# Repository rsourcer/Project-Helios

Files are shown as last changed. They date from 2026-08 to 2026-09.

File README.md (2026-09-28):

# Helios-Michaelson-Interferometer
Digitally assisted optical platform using a Michaelson Interferometer allowing for magnetostriction testing using red laser light. 

A **Michaelson Interferometer** is a typical configuration for interferometry in which a laser first hits a beamsplitter. The light is roughly equally split, travelling in two perpendicular directions, but hit a mirror, which bounces both beams back to the beamsplitter. This makes the light recombine in a strange way, creating a rippling effect and travelling in a completely new direction. The change in light intensity caused by these ripples as one of the mirrors moves can be measured by a photodiode and can be used to calculate the wavelength of the light to, in theory, calculate the phase shift caused by a magnetic field caused by a solenoid. This is done with the formula
$$\lambda = \frac{2d}{\Delta N}$$ , where d is the distance the mirror moves by and ΔN is the number of fringes observed.
In turn, it is therefore possible to measure a **magnetostriction** strength using a mirror attached to a metal rod inside a solenoid - as the magnetic field affects the rod, the mirror moves, and the fringes shift in a measurable manner.
<div align="left">
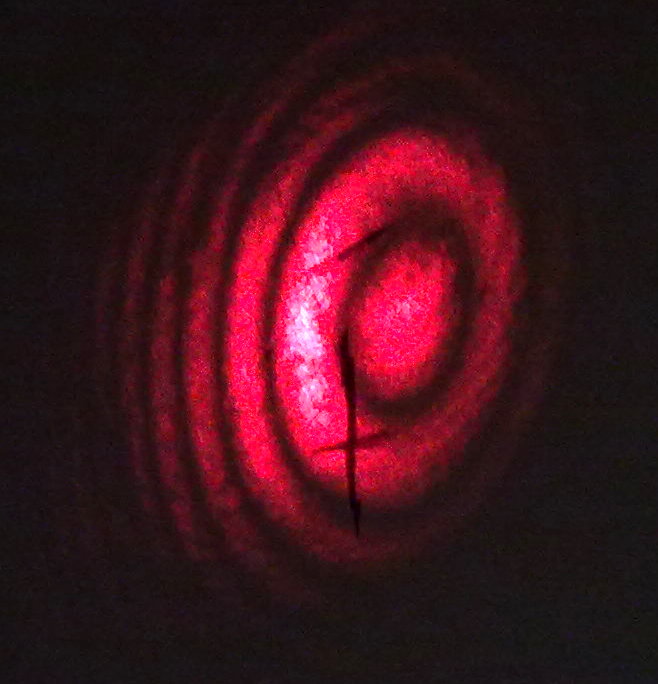
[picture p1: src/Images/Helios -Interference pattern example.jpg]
  
</div>
Fig 1.01: Example of an enlarged fringe image produced by a michaelson interferometer. (Wikipedia Commons) [1]

The aim of this project is therefore to detect fringe shifts caused magnetostrictive strain. The object's technical objective is to build a Michaelson Interferometer system which can:
- Takes a laser diode's output
- Splits the light through a beam splitter component
- Recombine light with the help of two mirrors, creating the interferometric patterns crucial to the experiment
- Project the image onto a photodiode or expand it with a lens
- Detect interference patterns using a TIA photodiode system as one of the mirrors moves parallel to the laser light.
- Detect magnetostriction through fringe movements spotted by the photodiode's signal output\
See JOURNAL.md for further constraints and objectives.

# Hardware:

|  |  |
|:---|:---|
| **Optics** |  |
| Laser Diode | Budget 650nm Laser|
| Beam Splitting Glass | Budget 50:50 Cube Beamsplitter|
| Mirrors | 2x λ/10 Flatness Protected Silver, Ø1/2" Mirror |
| Lens | 160/0.17 10X Achromatic Objectives Lens |
|**Electronics** | |
| Board | Arduino Uno ATmega328P |
| Amplifier | MCP601-I/P |
| Capacitor | 100 pF Capacitor | 
| Photodiode | BPW34 |
| Resistors | 100kΩ 25 Turn Trimmer + 100Ω Fixed Resistor|
| Rod | Nickel Rod |
| Solenoid | Made from Copper Wire |
| Power Supply | DC Variable Power Supply |
|**Mechanical** | |
| Micrometer | 0-13mm Micrometer Flat/Ball Head |
| Screws | 10x Assorted M3, M5, M6 Screws w/Nut & Washers, Heat Insert set |
| Brackets, mounts | 3D Printed from PETG-CF |
|**Miscellaneous** | |
| Breadboard | Adapted CNC MDF 3040 Spoilboard, 30x36cm |
| Image Surface | Grid Paper |

# Acronym List:

This is a reference to understand every acronym used

Optical\
BS: Beamsplitter\
M1: Mirror 1 (Micrometer mirror)\
M2: Mirror 2 (Solenoid mirror)\
PD: Photodiode\
Electronics\
PS: Power Supply\
NR: Nickel Rod\
S or SLD: Solenoid\
AMP/TIA: Trans-Impendence Amplifier\
Mounts\
BSM: Beamsplitter mount\
LDM: Laser diode mounting bracket\
LMB: Lens mounting bracket\
SMM/SMB: Solenoid mirror mounts/bracket\
MMM: Micrometer mirror mounts\
PMB: Photodiode mounting bracket\
SPB: Spoilboard

# 3D Models
- To print all components, the stl files were used and sliced into gcode- this may lead to inconsistencies when using the step file, as it was converted online! Please beware of this if trying to print models.\
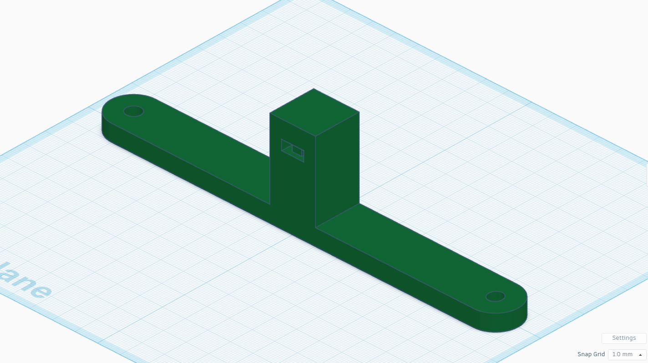
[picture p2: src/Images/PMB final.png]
  \
  Fig 1.02: Finalized version of the PMB.\
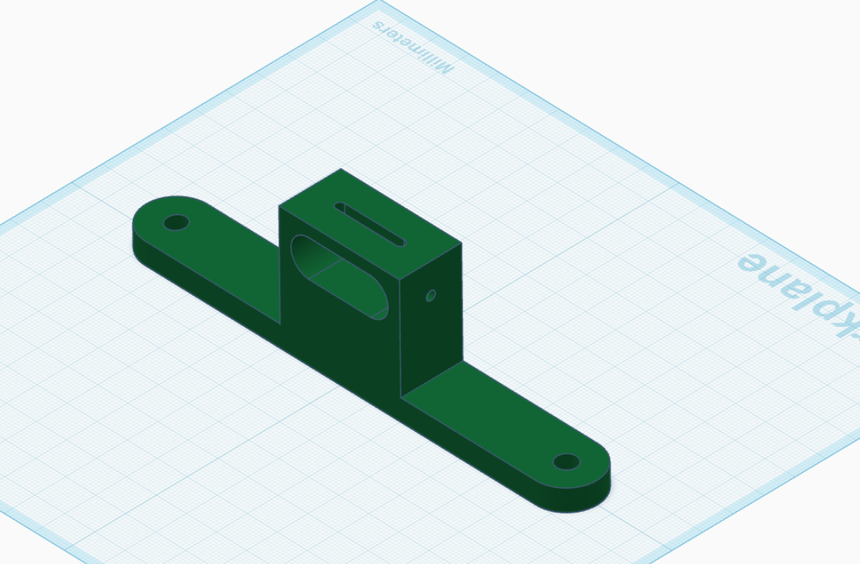
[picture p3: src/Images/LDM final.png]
    \
  Fig 1.03: Finalized version of the LDM.\
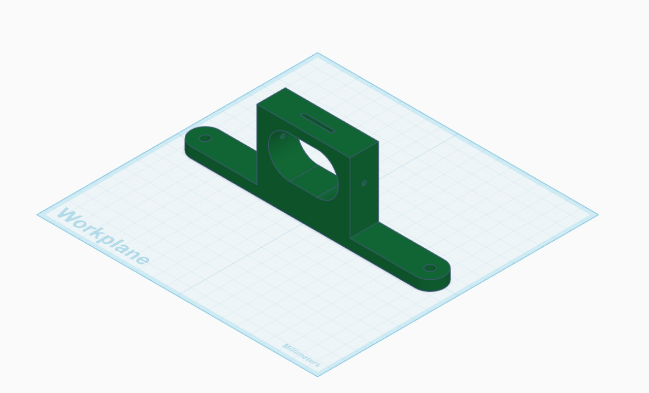
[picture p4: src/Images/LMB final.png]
    \
  Fig 1.04: Finalized version of the LMB.\
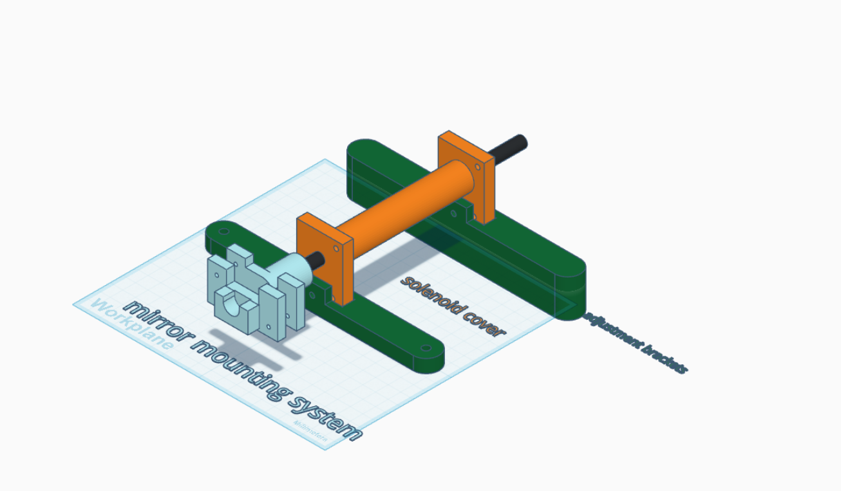
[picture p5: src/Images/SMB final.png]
    \
  Fig 1.05: Finalized version of the SMB.\
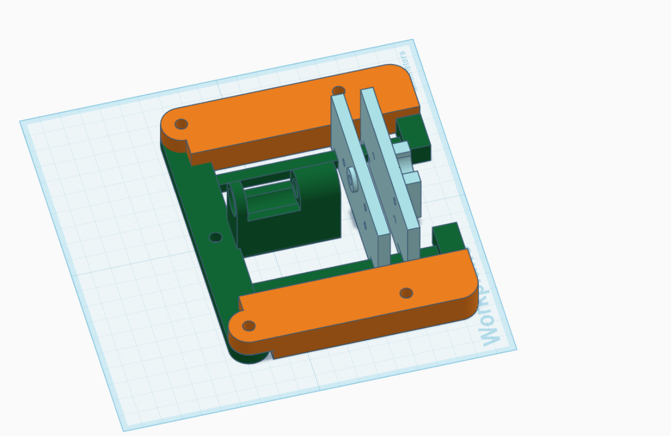
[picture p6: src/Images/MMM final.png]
    \
  Fig 1.06: Finalized version of the MMM.\
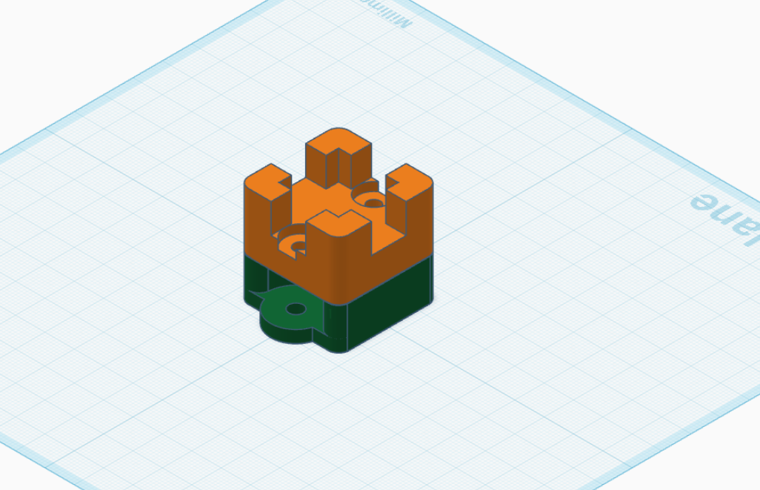
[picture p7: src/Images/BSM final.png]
    \
  Fig 1.07: Finalized version of the BSM.\
# Testing Checklist

**Preparation**
---
1: Prepare a clean, flat surface to work on.\
2: Use a vacuum cleaner on work surface and isolate ventilation of room to ensure no dust enters. Ideally, use an air purifier to mitigate dust further.\
3: Wear disposable gloves to ensure touched components remain dust free.\
4: Gently take out the beam splitter out of container, while holding its edges. Avoid contact with flat surface.\
5: Place the beam splitter flat onto the BSM mount.\
6: Gently take out the mirror while holding its circular edge - a plier may be used to facilitate removal from the case and precise insertion.\
7: Place the mirror onto the MMM mirror mount whilst avoiding contact between the plastic mount and the silvered surface.\
8: Repeat steps 7-8, but place the mirror onto the SMB mirror mount instead.\

**Calibration**
---
1: Connect ATMega32P to power.\
2: Using the spoilboard ruler markings, ensure L1 (distance from mirror 1 to beamsplitter) is within a millimeter's difference from L2 (distance from mirror 2 to beamsplitter) and that the micrometer is not fully extended.\
3: Use piece of cut paper to determine where laser images are at key points (beside the laser origin and in front of the lens)\
4: Align accordingly using screw mounts until all images land at the same place (on the beam)\
5: If needed, adjust lens position precisely using translation screws until the recombined beam is at the lens center.\
6: If needed, adjust laser focal length with focal adjustment guide until the beam does not visibly diverge or converge at a point, using the lens image and cut paper to measure laser size.

**Electronic Measurement**
---
1: If unconnected, connect the Photodiode anode to the 5V AtMega32P pin.\
2: Connect the GND wire from the op-amp's Pin 3 to the GND AtMega32P pin.\
3: Power on the AtMega32P and turn on the power supply.\
4: Precisely move mirror 1 using the permitted movement in the MMM until the signal modulation drops significantly on screen, making sure that the laser dot image hits the photodiode - this ensures the photodiode is measuring dips produced by Michaelson fringes!\
5: Gradually set power supply current to 10A in about 5 seconds. Be sure to remain as constant as possible.\
6:Observe change produced in photodiode signal.\
Further explanations are in the JOURNAL.md file - I recommend checking it out! 

# Electronics
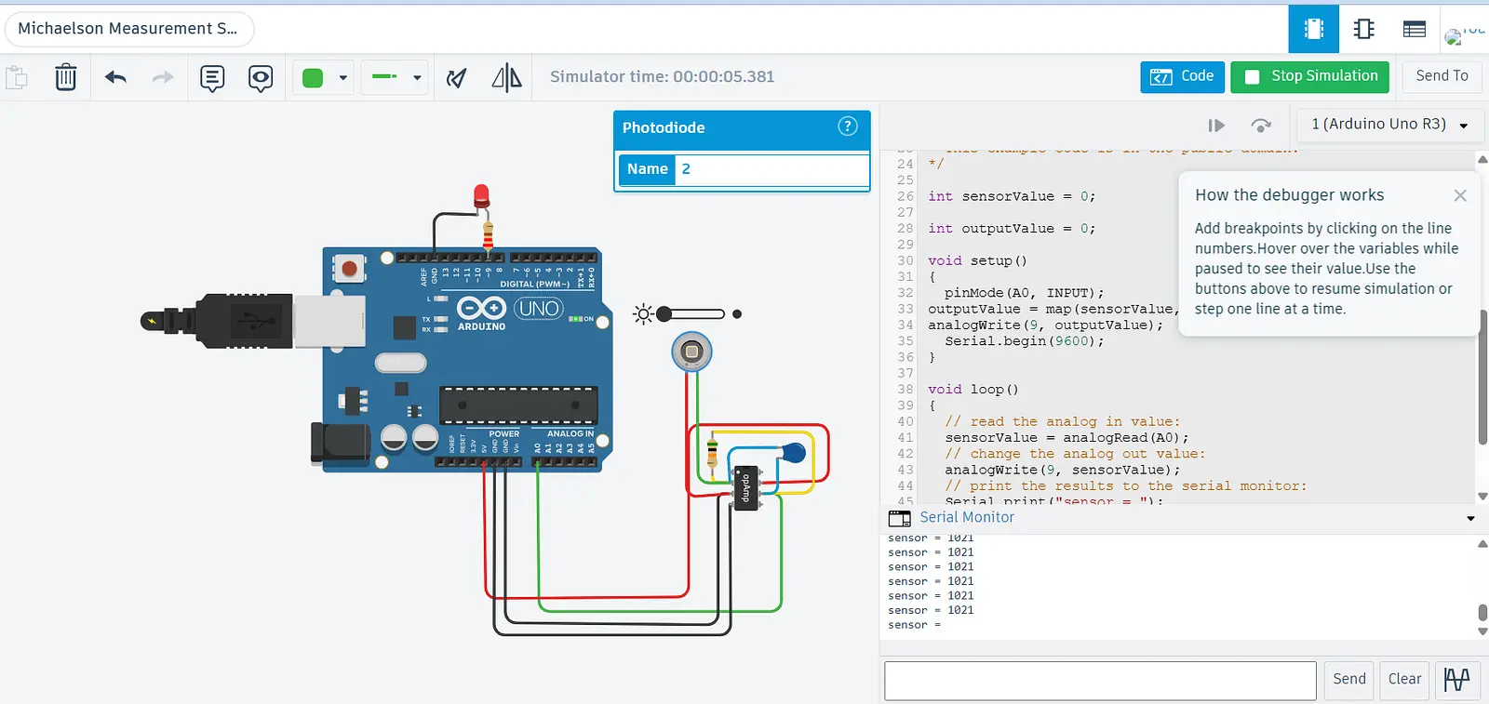
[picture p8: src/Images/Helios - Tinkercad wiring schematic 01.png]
  
  Fig 1.08: Original theoretical wiring for TIA amplification system for a photodiode.
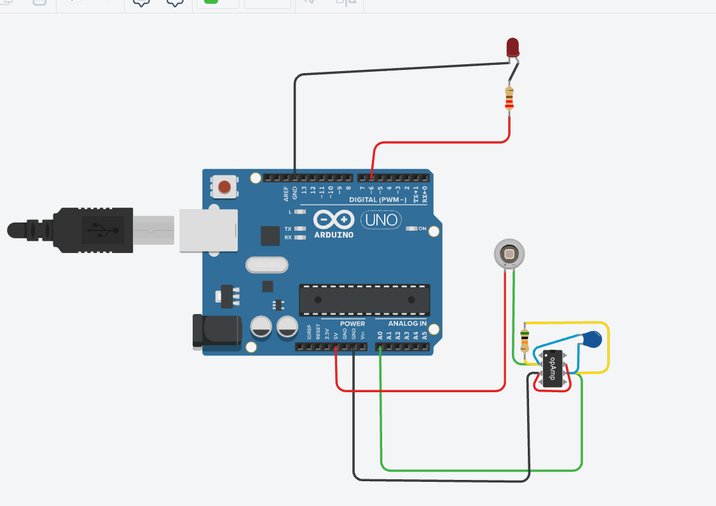
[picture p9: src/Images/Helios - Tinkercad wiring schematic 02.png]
 
  Fig 1.09: Real-world wiring for TIA amplification system used in trial results.

There are two electronic circuits which make up the interferometry platform. The first is pictured above - it passes 5V through an MCP601 op-amp paired with a BPW34 photodiode to receive and amplify light signals, connected to the microcontroller - also connected to the 3.3V power source is 100Ohm resistor in series with a 650nm red laser diode.

The second is a 10A,30V rated power supply in CC mode running through a 120 turn, 25ft copper wire to create a solenoid magnetic field, which is used to measure magnetostriction inside a nickel rod:\
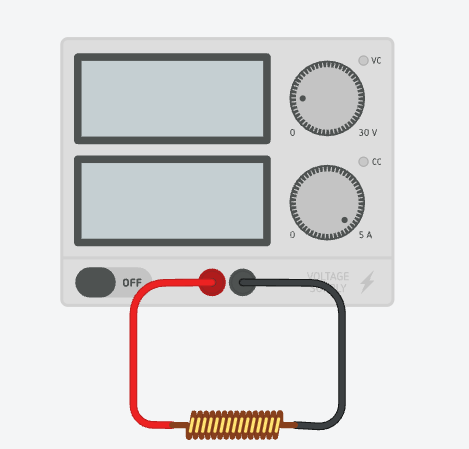
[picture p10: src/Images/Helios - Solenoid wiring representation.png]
 \
  Fig 1.10: Electrical wiring diagram of DC power supply with solenoid.
  
# Results
Following the Electronic Measurement protocol:
- A significant and repeated drop in signal strength of about 1.0(+-0.5) has been observed when the power supply current is increased at a steady rate.
- When the current is increased to 10A very quickly, the signal strength drops instantaneously.
- When the photodiode is fully covered, increasing the current does not affect it in any way.
Due to these factors, qualitative proof of the magnetostrictive properties of a nickel rod has been established beyond reasonable doubt, as the phase shift must can only have been caused by mechanical movement.
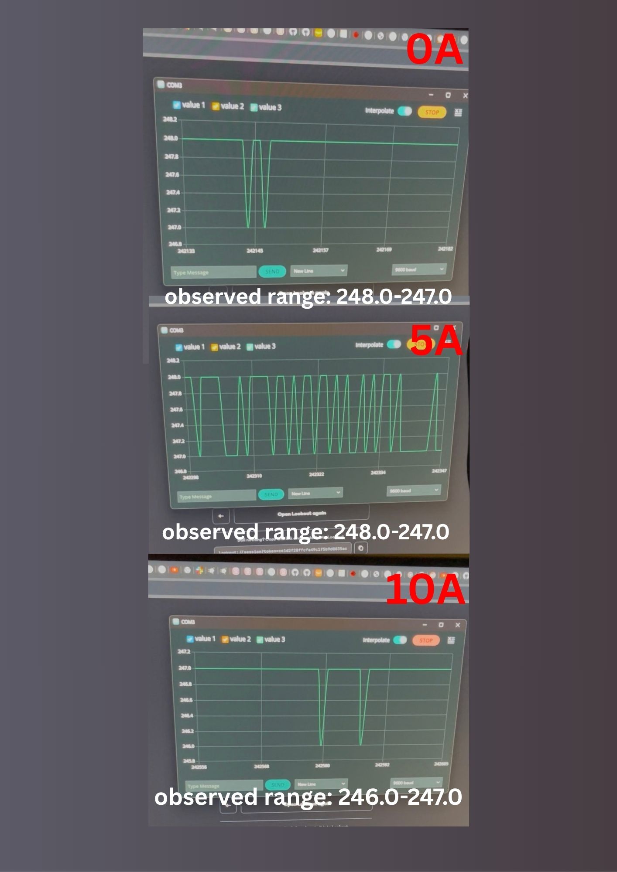
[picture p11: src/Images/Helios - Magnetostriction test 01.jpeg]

Fig 1.11: Representation of obtained results from magnetostriction, trial run 1.

Sources for this document:\
[1]

[Interference pattern Michelson Interferometer](https://commons.wikimedia.org/wiki/File:Interference_pattern.jpg) by Cecilia.p under Creative Commons Attribute 3.0 Unported

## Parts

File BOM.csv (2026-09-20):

Item Name | Qty | Price (CAD) | Item link | Notes
Thorlabs PFSQ10-03-P01 | 2 | $102.85 | https://www.thorlabs.com/item/PF05-03-P01 | ?/10 surface flatness, ?1/2" Protected Silver Mirror with 97% Reflectance @450nm. This item is priced in USD at 36.89 USD per mirror, so the Canadian price is accurate as of 11/08/2026. Shipping costs apply (35.45 USD -> $49.40)
Beam Splitter Cube, Optical Glass Dichroic Prism Ratio 50:50 Spectrome Sicence | 1 | $43.47 | https://www.amazon.ca/gp/product/B0B34FK2GF | K8 Cristal Cube Beamsplitter.
ELEGOO UNO Project Basic Starter Kit with Tutorial and UNO R3 | Compatible with Arduino IDE | 1 | $29.99 | https://www.amazon.ca/gp/product/B0834W2NKQ | ELEGOO Arduino UNO R3 board including jumper cables and spare resistors.
10x10PCS 1KV High Voltage Ceramic Capacitor Kit | 100pF 220pF 330pF 470pF 1nF 2.2nF 3.3nF 4.7nF 10nF 22nF | 1 | $10.99 | https://www.amazon.ca/gp/product/B0C5SKHXYD | Capacitor Kit with 10 sets of 10 capacitors, ranging from 100pF to 22nF.
MCP601-I/P | 3 | $2.94 | https://www.digikey.ca/en/products/detail/microchip-technology/MCP601-I-P/305930 | Op-Amp with single rail 2.7-6V support - all used pins match to the IC 741. DigiKey products are subject to 15$ shipping cost for both items as they amount to under 100$ CAD in purchases.
BPW34 | 2 | $5.78 | https://www.digikey.ca/en/products/detail/ams-osram-ag/BPW34/607274 | Photodiode rated for 850nm, 20ns. DigiKey products are subject to 15$ shipping cost for both items as they amount to under 100$ CAD in purchases.
uxcell 10Piece 3296W-104 100K Ohm Trimmer Pot Cermet Potentiometer | Variable Resistors | 1 | $12.50 | https://www.amazon.ca/gp/product/B00D2JRALS | 10x set of 25 turn, 100k Ohm Trimmers.
Inside Micrometer, 0-13mm Micrometer Flat/Ball Head | 1 | $18.67 | https://www.amazon.ca/gp/product/B083KHFKZ6 | 0-13 0.01mm Micrometer Head
DM-WJ002 185 Biological Microscope Objective Lens Silver 10X Achromatic Objectives Lens 160/0.17 | 1 | $21.96 | https://www.amazon.ca/gp/product/B082P3P953 | 10X Aluminium Achromatic Objective Lens.
Genmitsu 3040 MDF Spoilboard, Work with 3040 Y-Axis Extension Kit, 3018 CNC Upgraded Accessories Compatible with Most 3018, 3018-PRO/ 3018-MX3, 30 x 36 x 1.5cm (11.8'' x 14.1'' x 0.6'') | 1 | $29.74 | https://www.amazon.ca/Genmitsu-Spoilboard-Extension-Accessories-Compatible/dp/B08VN6HXPD | 30x36cm M5-6 compatible Spoilboard. Product is on sale as of 11/08/2026 and was ordered for this price. Usual price is 34.99$ CAD.
SHONAN Nickel Anode- 7.87"x0.3"(Diameter) Nickle Anode, Pure Nickel Bar, Nickel Rod for Nickel Electroplating Solution, 3.4oz 99.6% | 1 | $23.10 | https://www.amazon.ca/gp/product/B083LJWQYG | 7.87"x0.3" 99.6% Solid Nickel Rod.
123109-18GA Copper Wire 25FT 14LB | 1 | $9.99 | https://www.amazon.ca/gp/product/B000H5OL30 | 25 FT Polished Copper Wire. Product is on sale as of 11/08/2026 and was ordered for this price. Usual price is 11.99$ CAD.
Laser Diode Module 650nm 5mw Red Diodes 2Pack(Dot) | 1 | $8.95 | https://www.amazon.ca/Qiaoba-Laser-Diode-Module-Diodes/dp/B07L416LV1 | 650nm Red Laser Diode (2 pack).
520PCS Hex Bolts Nuts Washers Combination Kit, 304 Stainless Steel, Metric M3 M4 M5 M6 Hex Nuts and Bolts, Full Thread Mechanical Screws, 12 Commonly Used Sizes | 1 | $20.79 | https://www.amazon.ca/dp/B0GCRDQ8RG | 520 pcs set of assorted Hex Bolts, Lock/Flat Washers and Nuts ranging from M3-M6, length from 10mm-40mm. Product is on sale as of 23/08/2026 and was ordered for this price. Usual price is 22.09$ CAD.
Soft Tip Silicone Super Air Blower Blaster Pump Dust Cleaner Include Micro Fiber Cleaning Cloth, Bulb Blower | 1 | $13.99 | https://www.amazon.ca/dp/B07Y1TKXVK | Bulb air blower .
ZEISS Pre Moistened Sunglasses Cleaning Wipes, 120 Count | 1 | $20.69 | https://www.amazon.ca/dp/B0FT4WPV5F | 120x set of optical cleaning wipes. Product is on sale as of 09/13/2026 and was ordered for this price. Usual price is 22.99$ CAD.
300PCS Compression Springs Assortment 23 Sizes | 1 | $13.99 | https://www.amazon.ca/dp/B0GWZDRFBZ | 300x set of compression springs supporting M3-M6 screws
Shipping (Digikey) |  | $15.00
Shipping (THORLabs) |  | $49.40
Price before shipping costs (CAD): | $390.39
Subtotal (CAD): | $454.79
Price after sales tax (CAD): | $523.01

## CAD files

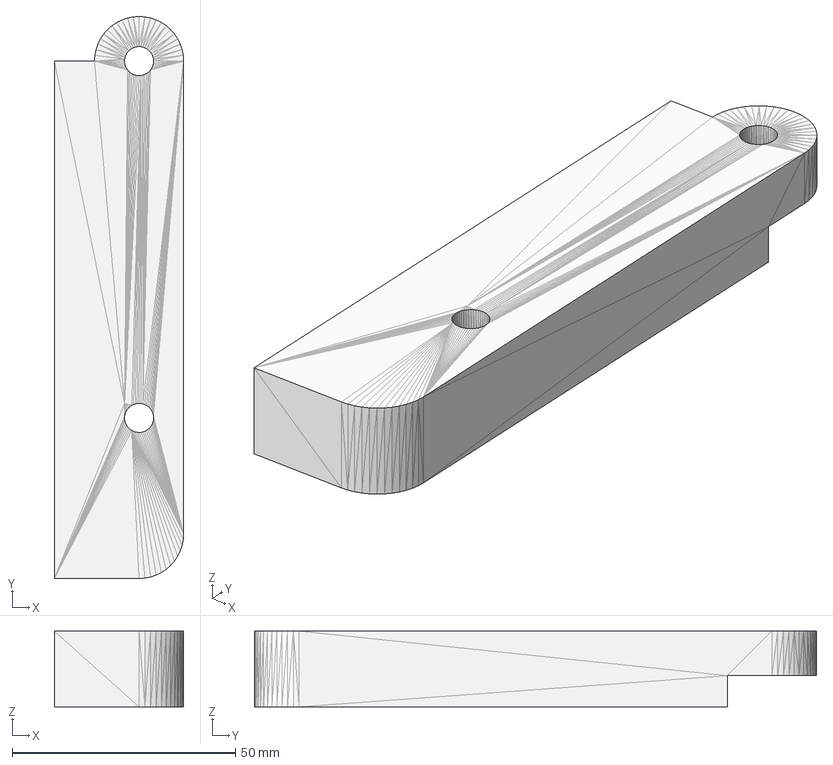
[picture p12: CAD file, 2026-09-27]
src/cad/final/.step files/MMM01.3.step
29.0 x 126.0 x 17.0 mm

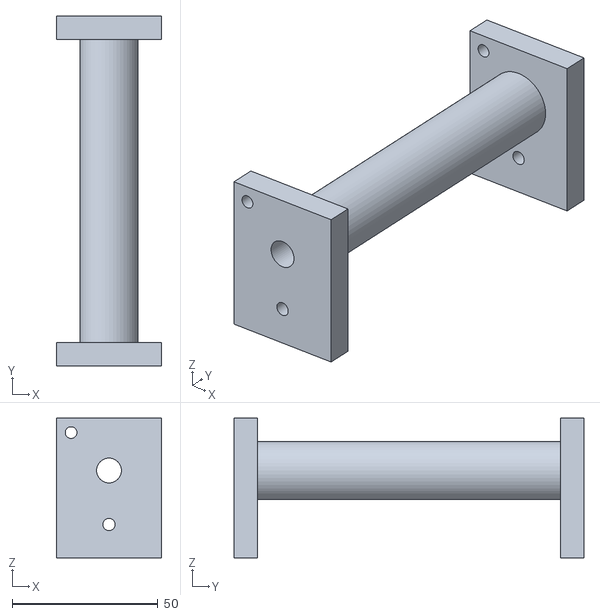
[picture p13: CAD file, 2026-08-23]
src/cad/final/SMB01.2.stl
36.0 x 120.0 x 48.0

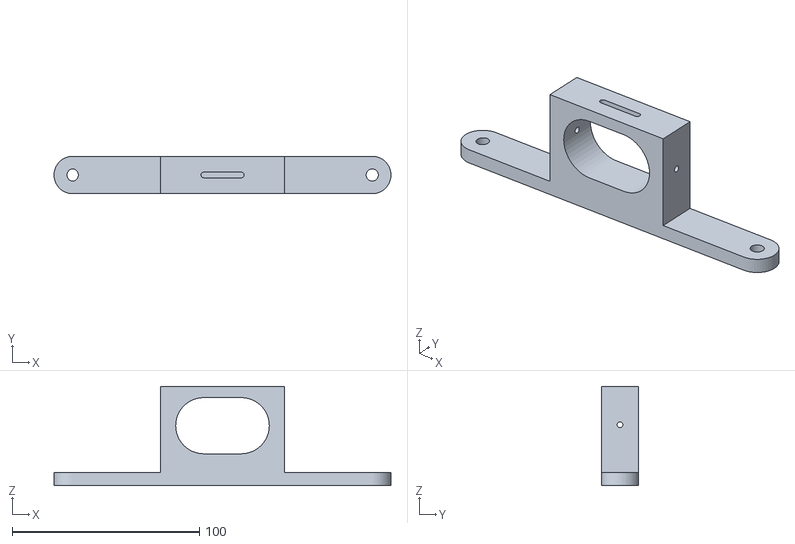
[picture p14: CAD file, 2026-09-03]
src/cad/iterations/LMB04.stl
180.0 x 20.0 x 53.0

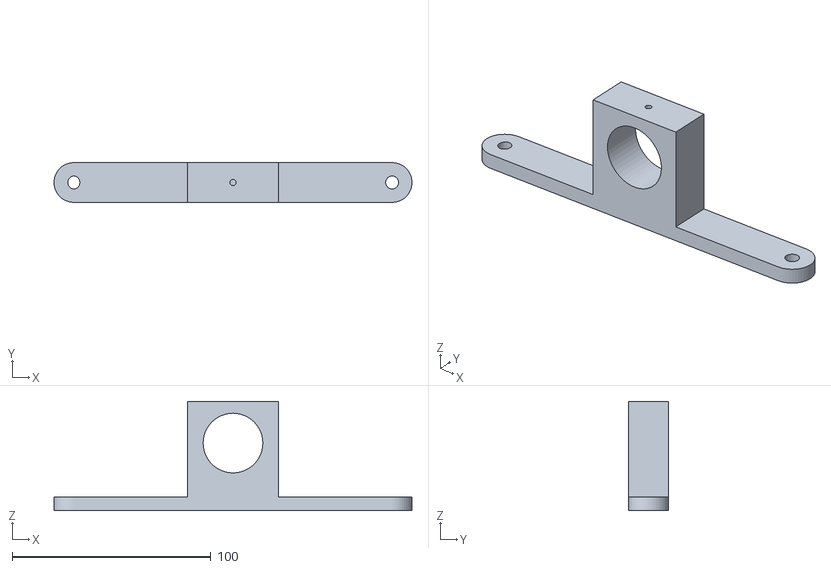
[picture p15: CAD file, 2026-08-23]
src/cad/final/LMB02.stl
180.0 x 20.0 x 55.0

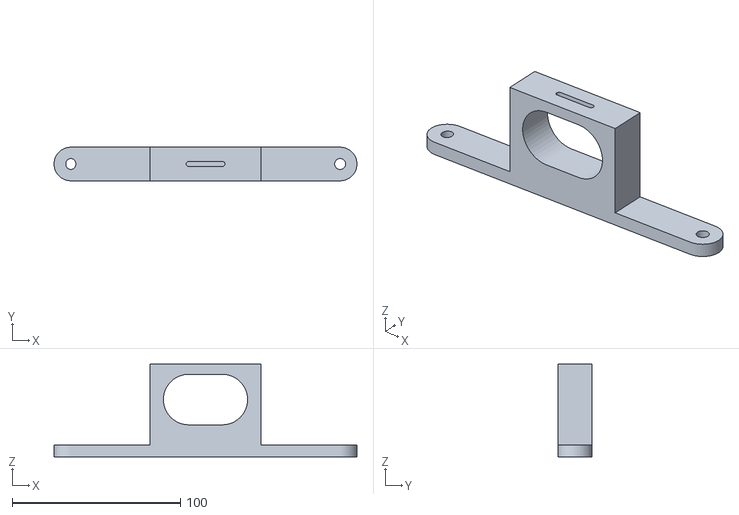
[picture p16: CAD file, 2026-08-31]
src/cad/iterations/LMB03.stl
180.0 x 20.0 x 55.0

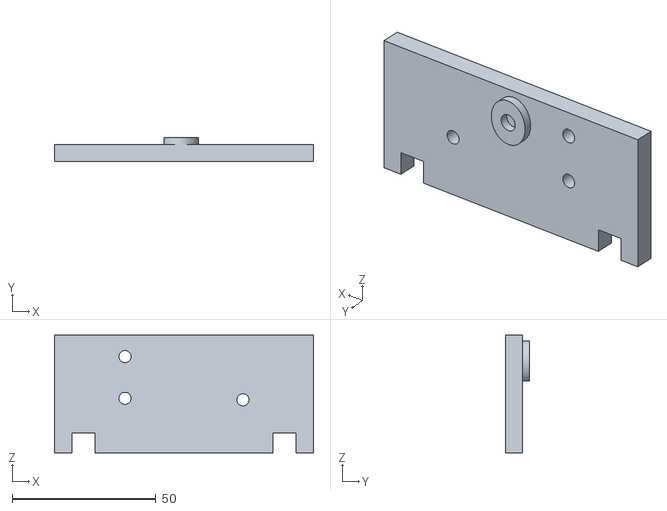
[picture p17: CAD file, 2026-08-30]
src/cad/iterations/MMM06.5.stl
90.0 x 8.50 x 41.0

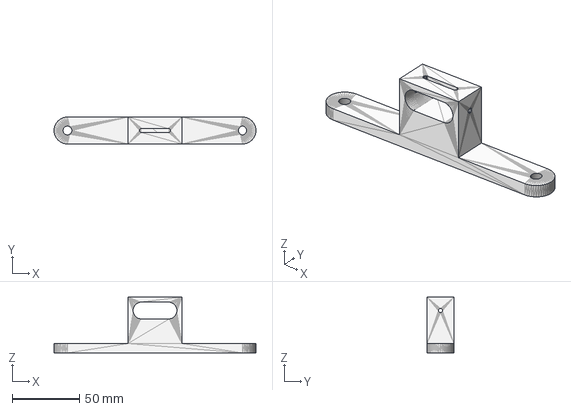
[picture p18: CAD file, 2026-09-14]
src/cad/final/.step files/LDM06.step
150.0 x 20.0 x 41.5 mm

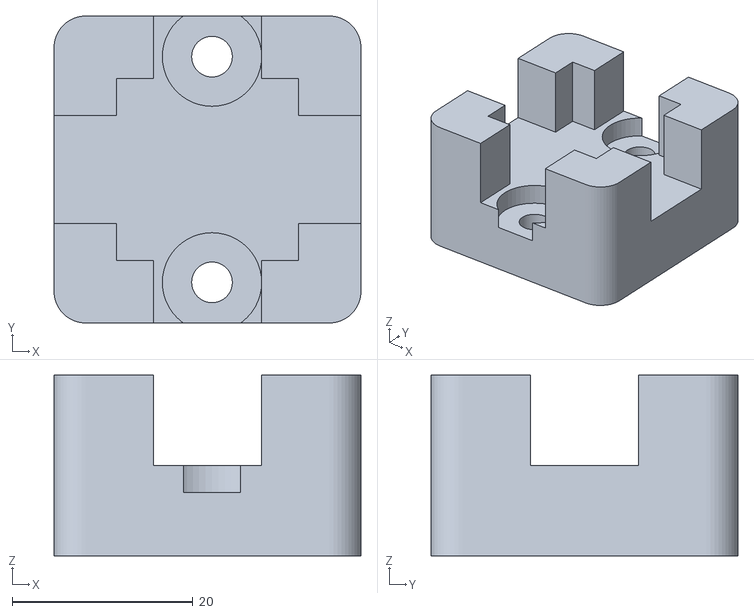
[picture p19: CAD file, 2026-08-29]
src/cad/iterations/BSM02.1.stl
34.0 x 34.0 x 20.0

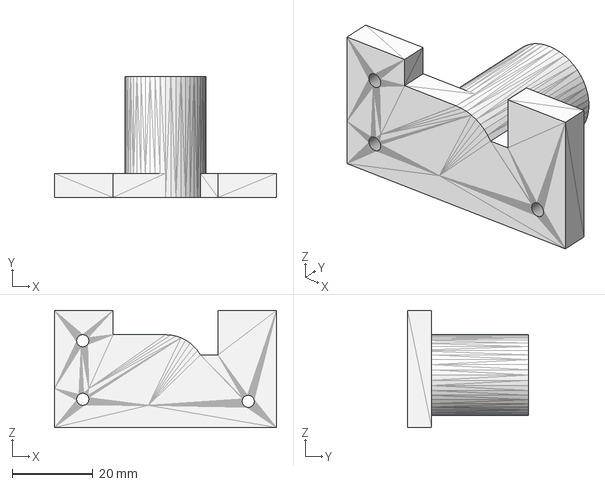
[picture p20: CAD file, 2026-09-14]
src/cad/final/.step files/SMB01.4.step
55.0 x 30.0 x 29.0 mm

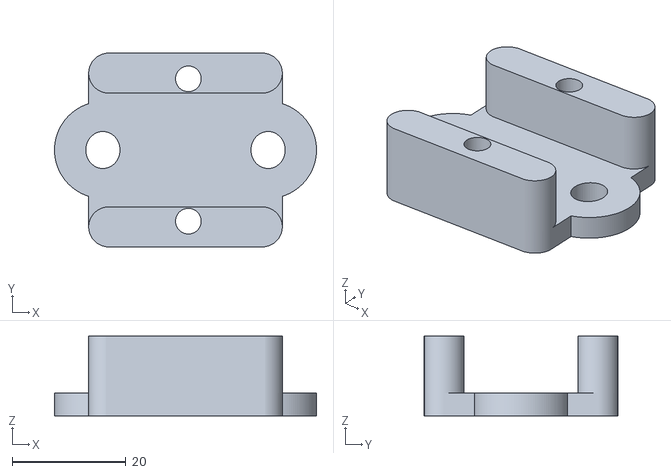
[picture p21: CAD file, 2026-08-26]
src/cad/iterations/BSM02.2.stl
46.0 x 34.0 x 14.0

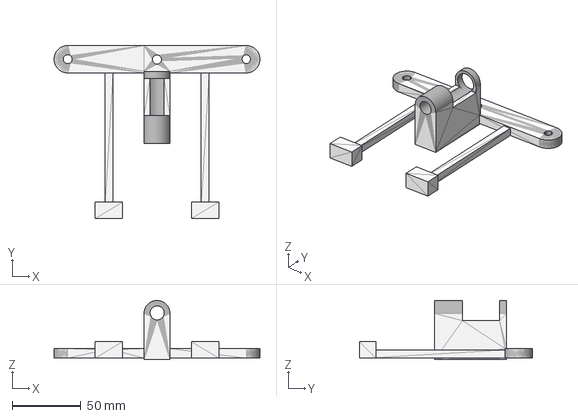
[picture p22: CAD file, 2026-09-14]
src/cad/final/.step files/MMM05.1.step
150.0 x 126.0 x 43.0 mm

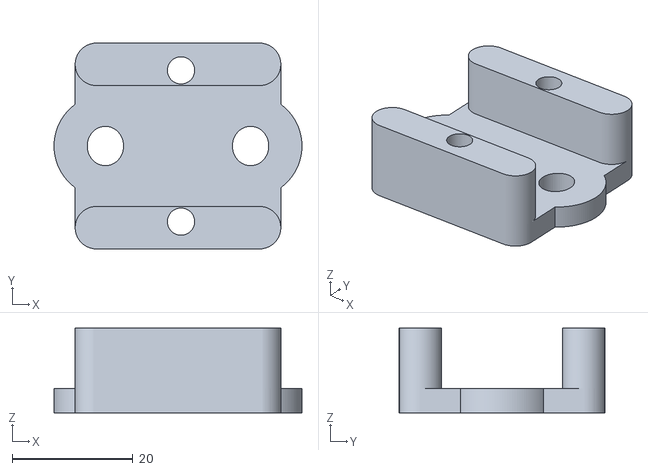
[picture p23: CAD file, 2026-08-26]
src/cad/iterations/BSM01.2.stl
41.0 x 34.0 x 14.0

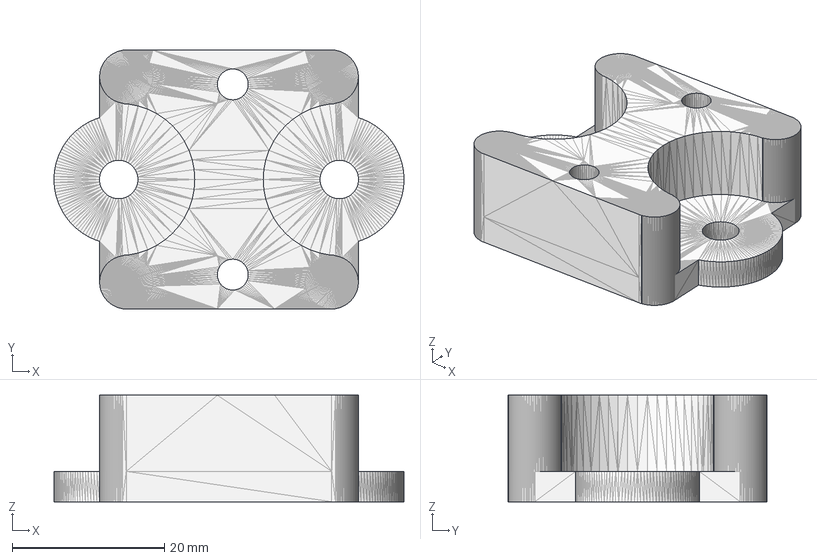
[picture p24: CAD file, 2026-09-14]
src/cad/final/.step files/BSM03.2.step
46.0 x 34.0 x 14.0 mm

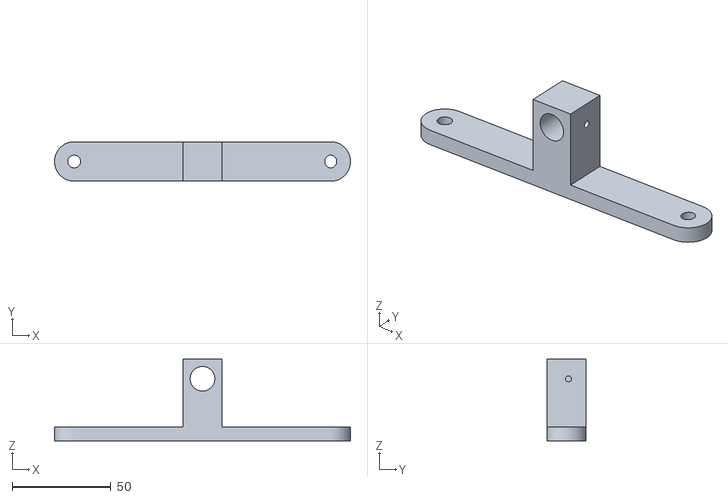
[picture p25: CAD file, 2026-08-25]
src/cad/iterations/LDM05.stl
150.0 x 20.0 x 41.5

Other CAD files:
src/cad/final/.step files/MMM01.2.step
src/cad/final/.step files/MMM.05.4.step
src/cad/iterations/BSM01.1.stl
src/cad/final/.step files/MMM07.5.step
src/cad/final/.step files/LMB05.step
src/cad/final/.step files/PMB01.step
src/cad/final/.step files/SMB01.1.step
src/cad/final/.step files/SMB01.3.step
src/cad/final/.step files/SMB01.5.step
src/cad/final/.step files/SMB02.2.step
src/cad/final/BSM03.2.stl
src/cad/final/LDM06.stl
src/cad/final/LMB05.stl
src/cad/final/MMM.05.4.stl
src/cad/final/MMM01.2.stl
src/cad/final/MMM01.3.stl
src/cad/final/MMM05.1.stl
src/cad/final/MMM07.5.stl
src/cad/final/PMB01.stl
src/cad/final/SMB01.1.stl
src/cad/final/SMB01.3.stl
src/cad/final/SMB01.4.stl
src/cad/final/SMB01.5.stl
src/cad/final/SMB02.2.stl
src/cad/iterations/LDM01.stl
src/cad/iterations/LDM02.stl
src/cad/iterations/LDM03.stl
src/cad/iterations/LDM04.stl
src/cad/iterations/LMB01.stl
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

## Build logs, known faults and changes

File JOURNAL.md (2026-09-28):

**Engineering Log for Open Source Michaelson Interferometer**\
**Revision 0.4.1\
Raoul Salemi\
This log is accurate as of 28/09/2026, 5:58 PM EST\
\
This document is to keep track of and formulate daily ideas along the course of this project. This will include any research, objectives, constraints and thoughts.

# **About this project**

The object's technical objective is to build a Michaelson Interferometer system which can:
- Takes a laser diode's output
- Splits the light through a beam splitter component
- Recombine light with the help of two mirrors, creating the interferometric patterns crucial to the experiment
- Project the image onto a photodiode or expand it with a lens
- Detect interference patterns using a TIA photodiode system as one of the mirrors moves parallel to the laser light.
- Detect magnetostriction through fringe movements spotted by the photodiode's signal output

Given this, it could then be able to:
- Accurately calculate wavelengths (defined later) based off mirror's movement from the micrometer's translation.
- Determine magnetostriction constant of a solenoid on which a mirror is mounted, based off the change in position of the aforementioned mirror.

**The formula for measuring wavelength as the mirror moves is**\
$$\lambda = \frac{2d}{\Delta N}$$  Where d is the distance between fringes and ΔN is the number of fringes observed.\
\
However, Michaelson Interferometers also prove very useful for a variety of experiments, one of such being magnetostriction. While the mirror attached to the micrometer stays static, this studies the change of distance in another mirror, facing the photodiode, once mounted to the edge of a ferromagnetic sample rod. As a magnetic field is contained inside it, the rod can either expand or contract, changing the mirror's position. We can therefore measure its magnetostriction constant by first, finding out how much the change in size of the coil through the movement of the mirror, with the formula:\
\
$$\Delta L = N_{fringes} \cdot \frac{\lambda}{2} $$\
Where N_{fringes} is the amount of peaks seen in the photodiode signal and λ is the laser wavelength. Then, use\
$$\lambda_m = \frac{\Delta L}{L_0}$$\
Where L0 is the length of the unmagnetized rod, and λm is the magnetostriction strain. Then, to find the field strength of the rod, H, we can use \
$$H = \frac{N \cdot I}{l}$$\
Where N is the number of turns in the coil, I is the current, and L is the length of the coil.
Finally, if we increase H (by raising the current) until dL plateaus and reaches a stable value, λm will be equal to the magnetostriction constant for the metal, λs.\
\
\
The optical phase shift of the light can also be calculated, and varies by \
$$\Delta \phi = \frac{4\pi \Delta L}{\lambda}$$
[1]
# **Components needed**

*Optical:*
- Laser Diode \
	The laser diode is what provides the system with an initial, focalized and uniform light source, crucial for the interferometry experiment as its intensity will be measured. It will be recycled from the DVD drive.
- Beam Splitting Glass (Cube/Flat)\
	This component splits the rays of light emitted by the laser light and sends them towards the parallel and perpendicular mirrors when at a 45 degree angle respective to the laser diode. It is important that this part splits the light evenly, as uneven distribution could alter results.
- 2x Reflective Flat Mirror\
	The mirrors reflect the light back to be recombined towards the beam splitter, which is what causes the interference effect - light acting on itself at the same place, cancelling itself out. λ/4 optical precision or higher would be wanted for such mirrors to ensure their accuracy for interferometry, while keeping them at a reasonable price point.

- Optional: Compensating glass plate\
	In multi-wavelength light applications, this is crucial for accuracy, and makes sure that light of all wavelengths travel through the same amount of glass no matter where the beam splitter sends them. Without it, with multiple wavelengths, refraction effects make the light much less useful for experimentation. This isn't needed at all if we have a cube beam splitter, as the light passes through the same amount of glass in those circumstances. [2]

*Mechanical:*
- Mirror adjustment system (M3 screws, plates, micrometer)\
	This is to adjust where the mirrors are on the system, fixing them in place yet allowing 1 axis of translational movement. One of the mirrors should also be connected to the rod inside the solenoid for magnetostriction testing. The other moves attached to a micrometer head: This will be used for determining the experimental wavelength of the laser. As the mirror moves
- Micrometer \
	This is to very precisely adjust the distance along which the mirror will move: as the mirror moves further into and out of the ray, the fringes will vary causing a change in light intensity in the photodiode. This signal is what will be used to calculate the wavelength of the light, depending on how far the mirror moves - therefore, high precision for its movement is important. It should also be able to lock into fixed position when the coil's magnetism is being tested, too.
- Mechanical Breadboard\
	This will be a solid starting plate to place all our components on, and fix them in place where they are desired.

*Measurement/Calibration:*
- Divergent Lens (Concave)\
	This enlarges the image of the interference fringes, allowing for calibration and visual testing (to make sure no unusual behaviour is produced). Short focal lengths preferred as the image should be enlarged quite a bit.
- Ground glass (any surface producing clean fringe image)\
	This is a surface to show the clear interference pattern enlarged by the lens.

*Electronics:*
- Photodiode sensor\
	This component picks up the recombined light emitted by the laser and sends electrical pulses based on the light's intensity.
- Amplifier\
	Amplifies the photodiode's detection of the laser, filtering out all other muddying noise.
- Arduino Uno (or alternative)\
	Processes the signal from photodiode, allowing the data to be analyzed from a computer.
- Rod\
	During magnetostriction tests, a mirror is mounted onto it, and the rod expands/contracts as a magnetic field induced by the solenoid flows through it.
- Solenoid/Coil: \
	During magnetostriction tests, this is what induces a magnetic field on the metal rod.

*Software:*
- KiCad (for electronics schematics (?))\
- TinkerCAD (for visual representation)\
- Python (programming of electronics (?))\
- any 3d printing software (I have experience in Blender and Fusion 360)\

# **Constraints** 

- BUDGET: 350 CAD
	The project must be a relatively low-cost solution. Professional interferometry equipment can be very expensive - at the time of writing, according to the website Edmunds, the cheapest available cube beam splitter alone, is 389 CAD, [3]. These beam splitters are considered rather standard for professional Michaelson optics projects. Using such optical grade components, it is highly unrealistic to build the interferometry platform within this budget range. It is to note that cheaper types of beam splitters do exist, and this budget will incentivize innovative usages for components. I will exclude shipping costs and taxes as I want to truly focus on the factor of value for the money the product itself costed - how much the manufacturer is selling it for.

- Recycled components
	While doing preliminary research in DIY interferometry, it struck my eye that many projects use recycled components to achieve their goals with relatively much power cost, while still retaining rather high precision. (3 Project Examples) Within that context, this project, too, must make creative use and source components from at least one recycled item - a component for which the intention of procurement was not originally interferometry or any other optical experimentation.
- Magnetostriction element
	The platform must be able to observe the effects of magnetostriction through a solenoid. This is the end goal of the interferometer, as it shows a real world application in which it can be used, beyond determining the wavelength of the laser diode. Doing so, it must also pass the precision aspect of the project.

- 3D Printing aspect
	To build a Michaelson interferometer, precise adjustment of distances is needed. Therefore, it would be reasonable to use my 3D printer, to this end. An important secondary goal of mine would be to test structural elements of pieces printed for this project from varying infill percentages and patterns, extrusion settings- etc, to make the most optimal 3D printed components for the interferometer. What defines "most optimal 3D printed components" will be defined later. My goal for this constraint is to further my knowledge of materials testing. 

- Precision aspect
	It would be futile to build an interferometer if it is not able to, well, interfere. Therefore, the uncertainty of the device's frequency measurements, once calculated (with electronic measurement technique - photodiode picks up signal from light intensity along the laser's shifting fringe patterns) must not be over +-10% in nanometers. For a given 650 nm light source, this means that the uncertainly should not be +-6.5 nm. There should be ≈10kHz bandwidth in the TIA circuit. During magnetostriction, λs should be calculated within a 10% margin of the expected value.

- Time aspect
	Given that the Stardance Hack Club project is ending on September 31st, it would be reasonable to finish this project by September 1st, 2026, as to not overlap with scholarly life. (to be removed?)

# **Assumptions**

	Laser wavelength ≈650 nm 
	Ambient temperature ≈20°C 
	System assembled indoors
	PETG-CF sufficiently stiff for preliminary testing

# **Acronym Legend**
Please refer to these if acronyms are used to describe components, such as in the project files.\
**Optical**
BS: Beamsplitter\
M1: Mirror 1 (Micrometer mirror)\
M2: Mirror 2 (Solenoid mirror)\
PD: Photodiode\
**Electronics**
PS: Power Supply\
NR: Nickel Rod\
S or SLD:  Solenoid\
AMP: op-amplifier
**Mounts**
BSM: Beamsplitter mount\
LDM: Laser diode mounting bracket\
LMB: Lens mounting bracket\
SMM: Solenoid mirror mount\
MMM: Micrometer mirror mount\
PMB: Photodiode mounting bracket\
# **Parts List**

**Laser Diode, springs:** From DVD Drive

**Mirrors :** 2x Thorlabs  **[PF05-03-P01](https://www.thorlabs.com/item/PF05-03-P01)**

**Beamsplitter:** Beam Splitter Cube, Optical Glass Dichroic Prism Ratio 50:50 Spectrome Sicence (20mm) ( Amazon) 
https://www.amazon.ca/gp/product/B0B34FK2GF

**Board, Wires, spare resistors:** ELEGOO UNO Project Basic Starter Kit with Tutorial and UNO R3 | Compatible with Arduino IDE (Amazon) 
https://www.amazon.ca/gp/product/B0834W2NKQ

**Capacitor set:** 10x10PCS 1KV High Voltage Ceramic Capacitor Kit | 100pF 220pF 330pF 470pF 1nF 2.2nF 3.3nF 4.7nF 10nF 22nF (Amazon) 
https://www.amazon.ca/gp/product/B0C5SKHXYD

**Op-Amp:** MCP601-I/P ( DigiKey MCP601-I/P-ND) 

**Photodiode:** BPW34 (DigiKey 475-BPW34-ND) 

**Resistor:** 0-100kOhm Trimmer (Amazon)

**Micrometer:** Inside Micrometer, 0-13mm Micrometer Flat/Ball Head (Amazon)
https://www.amazon.ca/gp/product/B083KHFKZ6

**Lens:** DM-WJ002 185 Biological Microscope Objective Lens Silver 10X Achromatic Objectives Lens 160/0.17 (Amazon)
https://www.amazon.ca/gp/product/B082P3P953

**Solid Mechanical Breadboard:** Genmitsu 3040 MDF Spoilboard, Work with 3040 Y-Axis Extension Kit, 3018 CNC Upgraded Accessories Compatible with Most 3018, 3018-PRO/ 3018-MX3, 30 x 36 x 1.5cm (11.8'' x 14.1'' x 0.6'') (Amazon)
https://www.amazon.ca/Genmitsu-Spoilboard-Extension-Accessories-Compatible/dp/B08VN6HXPD

**Magnetostriction rod:** SHONAN Nickel Anode- 7.87"x0.3"(Diameter) Nickle Anode, Pure Nickel Bar, Nickel Rod for Nickel Electroplating Solution, 3.4oz 99.6% 
https://www.amazon.ca/gp/product/B083LJWQYG

**Solenoid Wire:** # 123109-18GA Copper Wire 25FT 14LB
https://www.amazon.ca/gp/product/B000H5OL30

**Available already:**

2x DVD Drive (unknown model) 
Anycubic Kobra 3 + Ace Pro 2 
PETG-CF filament (1kg)
1kg Laser 190-2000nm protection glasses
NICE-POWER DC Power Supply Variable 30V 10A Adjustable Switching Regulated High Precision 4-Digits LED Display 5V/2A USB Port Output & Input Power Cord Bench Lab Power Supplies Digital Digital Multimeter
Soldering kit w/ wire, paste

Electric Drill w/ clamps for drilling through the wood board 
Computer 

**What I still need:** M3-6 screws required, with nuts, bolts and washers, assembly brackets, which can be 3D printed. These components can be purchased/created and implemented rather accessibly, so I figure that I should currently not worry about these until I have real world technical drawings.

# **Daily progress tracking**

	2026-07-23\
	Goal: Gain a concrete understanding of what I need for this project\
	Time spent: 48 min\
	Activities: Research, journaling (creation of this document, checking product listings\
	
	Decisions:  \
	 D-001 - I have opted to use an unused DVD drive to source many of the components for a Michaelson Interferometer\
	 
	Reason: This seems to be a common element of low cost solutions for this device: DVD drives come with laser diodes (640-660nm) , lenses and a semi transparent mirror, parts which have already been tested as useful for the creation of a Michaelson Interferometer in the past. [4]

Lingering Questions: What is the purpose of the compensator mirror? Why do some interferometer systems not use it? What precisional advantage could it offer?
Retroactive answer: The compensator mirror is used in multi-wavelength applications where the light must refract through the same amount of glass no matter where the beam splitter hits to obtain an accurate recombined image. Therefore, this glass serves to compensate for the side which bounces off the beam splitter initially. IT does not offer a precisional advantage in single wavelength applications. 

--------------------------------------------------------------------------

	2026-07-24\
	Goal: Better my mental picture of the required assembly\
	Time spent: \
	Activities: Setting up KiCad, sketching rough paper blueprint, researching required electronic components\
	
	Decisions:  \
	 D-002 - I have opted to have two variations of the system - one to calibrate the interferometer, consisting of a lens and a surface where the fringes will be visible - and one consisting of the electronic measuring components. This is to maximize the ease of precise set-up and reliable measurement precision of the respective methods.\
	 
	D-003 - I have opted to use an Arduino Uno R3 compatible clone rather than the official product to save cost. The Elegoo R3 is currently the most seemingly promising option. This will allow to maximize value elsewhere.\

Lingering Questions: Why must we need a capacitor and resistor for the circuit? How will using or not using an amplifier play into the measurement system?
Answer: When a photodiode receives light, it does not modify the voltage of the circuit in of itself, but the amount of current flowing through it. This is what allows us to get a signal. However, without an amplifier, the difference in current produced by the light can be minimal and prone to noise, greatly decreasing its efficiency. Therefore, the amplifier helps to mitigate the effects caused by noise, and get a much clearer picture of the laser's signal.

--------------------------------------------------------------------------
2026-07-26\
	Goal: Completely understand electronics aspects of the interferometry\
	Time spent: \
	Activities: Research on electronics equipment needed. Beginning a rough KiCad schematic.\
	
	Decisions:  \
	 D-004 - I have decided on what parts I will use - I will couple the Elegoo R3 as discussed yesterday with a BPW43 photodiode, as it is a photodiode suited for near-IR range, inexpensive and has lots of educational resources available. Coupled to these two components could be a UA741 op-amp, which seems to be a common pairing with this photodiode.[5]\
	
One thing which helped me today was the BPW43 photodiode tutorial [6], which helped me to further understand how the electronics of this project will function. \

Lingering Questions: Given my needed applications, should I really use KiCad? Should I create a PCB, or invest in a breadboard? What advantages and disadvantages would there be to this? Is this still a question for which it is too early to tell?\
Answer: ...No. There is no real benefit to remodel the circuit on KiCad as TinkerCAD already has a schematic model which works fine.

-------------------------------------------------------------------------------------------------------------
2027-07-27
	Goal: Finalize real electronic design and schematic\
	Time spent:\
	Activities: Journal refining, Researching TinkerCAD to further progress on electronics for my project\
	
	Decisions:  \
	 D-005 - I decided to use TinkerCAD to create a model of the TIA photodiode circuit, as many templates are available to choose from - this will make it easy for me to verify my circuit logic. It also has a much smaller learning curve than KiCad does.\
	
One thing which helped me today was the TinkerCAD photodiode preset, which shows how to make a (albeit less complicated) version of the photodiode system I seek to create. Using this, I can easily gain a clearer picture of what the electronics are supposed to look like once adapting it into a TIA design, as opposed to immediately jumping into KiCad and hoping to understand - what I felt I was doing in the previous days of research. This also allows me to pre-emptively program the circuit long before getting around to building it. (and, of course, some real world aspects are overlooked in TinkerCAD, so I can only use the code blocks offered as simple guidance). My course of action is now to use the simplified TinkerCAD model to understand the wiring, then, replicate it on KiCad now that I have improved my knowledge on how to use the program.

------------------------------------
2026-07-28\
	Goal: ACTUALLY finalize electronic design. Yesterday, I ran into a problem with the circuit which rather confused me. Today, I want to focus on getting this template TIA circuit running properly, as to understand what is going on.\
	Time spent:\
	Activities: Rewiring TinkerCAD Circuit, debugging said circuit.\
	
	 Decisions:\
		 D-006: I am reconsidering the usage of the UA741 op-amp, as it seems to be an unfit match for the current application. The supply is 5V, meaning that it falls on the short end of its rated voltage range (~4.5-40V) [7] While it could still be viable, other op-amps such as the OPA381 could be more effective for the task at hand. This would translate into real world implications for bettering our precision and accuracy results when testing our interferometer.\

I ran into many problems while debugging the TinkerCAD circuit to be operational. I based myself off a pre-existing default photodiode circuit template (credit to Tom Igor for the C++ code) and had to retrofit it into the TIA circuit system I will use. However, the amplifier proved to be very tricky to wire. Using my online resources, I had been able to get it in a way as to work in reducing the measured signal, which made the variance in intensity go from about 203 (from 10-213) to only 1 (from 512-513). I spent hours reconfiguring the circuit, testing changes - whether it be in wiring, resistance or capacitances - and using the software's built in voltmeter at different points until I had been able to bring the total variance up to.. 2 (from 0-2). From there, I changed the secondary ground pin from 5 to 3, which didn't work at all. However, once I reversed the polarity of the photodiode arbitrarily, the op-amp system suddenly worked. As much of a fluke this was, my work wasn't finished - about a quarter of the way up, the output values would sharply plateau at about 255, since it seems this was the maximum value the code allowed to output in this configuration (curiously, as of writing, the original version of the code works too). Nonetheless, after some research, I slightly tweaked the code by using the C++ `map `container to assign to a new outputValue variable:

```
outputValue = map(sensorValue, 0, 1023, 0, 255);
analogWrite(9, outputValue);
```

With that, the transimpendance amplifier circuit was now complete! :) It operates with values ranging from 0-1012, which is vastly better to filter out any noise which would previously have proved problematic.

2026-08-01\
	Goal: Further my understanding of Waves & Optics\
	Time spent: 4h20: N/A\
	Activities : I decided to take a Sample Final Exam for the Waves, Optics & Modern Physics course from Dawson College.\ 
	This day was not particularly related to the Michaelson Interferometer in of itself, but rather the key concepts governing optics. This is going to be the exact topic of a course set for next semester, and is tangentially related to the project. I found myself with new ideas on how to approach the magnetostriction elements of the project - to prepare myself for the next semester. Doing an actual phase shift related problem is something which, before the interferometer, I had never encountered previously, and helped to understand and derive actual equations for this project. It is recommended check the questions out, they are quite well made :)

2026-08-02\
	Goal: Post a devlog! Improve github documentation\
	Time spent:\
	Activities: Updated README.md to contain much more information than prior, as well as specific component listings which go a bit farther into specifics than this document does. Updated this documentation and posted my very first devlog.\
	
	 Decisions:\
	 D-007: I have decided to opt for a budget Cube beamsplitter option instead of relying on scrap parts from the DVD drive. This is to ensure 50R/50T behavior in the splitter glass. With budget in mind, I have found ~46$ alternatives to the prohibitively expensive Edmunds optics kits, allowing me to acheive much better precision in determining laser wavelength.\
	 D-008: I have opted to use a Nickel wire for my magnetostriction testing. This is because, unlike pure iron, it only expands over field strength increases, and does much more so than iron. It is also relatively easy to source.\
	 
A great source which helped me derive the equations seen at the start of this document and understand their meaning was the PHYWE magnetostriction document. [8]\

Lingering Questions: What advantage could the optical phase shift calculation provide? How exactly does it translate to increased precision for magnetostriction - could there be other formulas which take advantage of it to attain more precise data that I am missing?

2026-08-03
	Goal: Figure out WHAT I am buying for this project\
	Time spent: 3h11min\
	Activities:\
	1: I started by doing the most expansive research to date on my mirrors. This is because they are one of the only optical components I cannot substitute with parts found in the used DVD drive. Since the beginning of this documentation, I have been eyeing out various mirrors from Edmund's Canada due to concerns about shipping time and optical quality on other websites. However, I have began to move away from this idea, and I think I have found just the match for my project. I researched other websites which could fit my price range while still satisfying my needs and shipping in the allocated time, and found it difficult to be certain while shopping for Canadian only products - maybe not even currently being in Canada, is of no help.

---

| Mirror | Description | Cost per mirror (CAD) |
| --- | --- | --- |
| 1: Edmunds  [**5mm Dia Enhanced Aluminum, 4-6λ Mirror**](https://www.edmundoptics.com/p/5mm-dia-enhanced-aluminum-4-6lambda-mirror/2709/) | Very low precision (4-6 λ), especially for magnetostriction applications. Least expensive option - also comes in very small. 450-650 nm range. | 39.90$ |
| 2: Edmunds<br> [**15 x 21mm Enhanced Aluminum, 4-6λ Mirror**](https://www.edmundoptics.com/p/15-x-21mm-enhanced-aluminum-4-6lambda-mirror/5358/) | Same thing as the other mirror, but at least this one is much larger despite being at the same cost. 450-650 nm range. | 39.90$ |
| 3: Edmunds [**5mm Dia. Enhanced Aluminum, λ/4 Mirror**](https://www.edmundoptics.com/p/5mm-dia-enhanced-aluminum-lambda4-mirror/8652/) | This mirror is much better in terms of precision. It has a Surface Flatness (P-V) of λ/4, which is much better for my application. However, it is very small AND costly. 450-650 nm range. | 89.60$ |
| 4: Edmunds <br> [**12.5mm Dia. 400 - 750nm Broadband λ/4 Mirror**](https://www.edmundoptics.com/p/125mm-dia-400---750nm-broadband-4-mirror/54000/) | Handedly, broadband dielectric mirrors are much better for my range. They are also even more expensive. (200-700nm) | 97.30$ |
| THORLabs **[PF03-03-F01](https://www.thorlabs.com/item/PF03-03-F01)** | λ/10 surface flatness is incredible at this price point. It is unfortunately not intended for the laser's wavelength, so their table shows that roughly 82-83% of laser power should reach the photodiode A bit small, at 7mm. 250-450nm range. | 33.99 USD → 47.64$ |
| THORLabs **[PFSQ05-03-F01](https://www.thorlabs.com/item/PFSQ05-03-F01)** | This is the PF03-03-F01's slightly larger, square twin. It is slightly larger (12.7mm) and therefore cheaper per area of mirror purchased. Shipping time is reasonable, yet cost is 35.44 USD. Isn't accounted for but still significant. | 39.74 USD → 55.70$ |
| THORLabs **[PFSQ05-03-P01](https://www.thorlabs.com/item/PFSQ05-03-P01)** | This mirror is the same price and flatness as the PFSQ05-03-F01, however it is in silver rather than aluminium, thicker (possible disadvantage with the rod) and much more reflective at 450nm (97%). However, not much more details are present concerning the mirror's reflectiveness from 640-660nm.14 day shipping time for my location. Curiously, shipping costs are almost double (68.55$ USD) though these are technically not accounted for in my budget. | 39.74 USD → 55.70$ |

2026-08-03 (contd.)
	
	Decisions \
	D-009: I ended up deciding on the THORLabs PFSQ05-03-F01 for my interferometer. This is as the estimated shipping time is much more reasonable, yet the mirror retains the λ/10 flatness found in all THORLabs options.\
	
2026-08-05\
	Goal: Finish a full parts list for my project.\
	Time spent: \
	Activities: Buying the mirrors, which costed, 79.48 USD (110.78 CAD as of 2026/08/05) Creating a full parts list for ChatGPT to give feedback and to check personally if I had missed anything. The full parts list is, at this current time, included near the top of the journal. However, Here are my justifications for every purchase:\

---
1: Beam Splitting Glass

| Beamsplitter | Justification | Cost (CAD) |
| --- | --- | --- |
| **[Beam Splitter Cube, Optical Glass Dichroic Prism Ratio 50:50 Spectrome Sicence](https://www.amazon.ca/gp/product/B0B34FK2GF)** | This item is low cost and fabricated with K8 Cristal, which is a material of sufficient grade for my project. The cheapest size is 20mm, which is more than enough. However, no precise manufacturer details are listed. I posit that it will still be good enough - cube beam splitters are preferred to flat beam splitters in terms of precision in Michaelson interferometer projects and similar optics. | 43.47$ |
This is frankly the only option I have considered which ships in reasonable time at this price point. Flat beam splitters of this material are available, but cube beam splitters are advantageous for my application. [9]

2: Board kit

| ATMega328P R3 Kit | Justification | Cost (CAD) |
| --- | --- | --- |
| **[ELEGOO UNO Project Basic Starter Kit with Tutorial and UNO R3 \| Compatible with Arduino IDE](https://www.amazon.ca/gp/product/B0834W2NKQ)** | This item comes with a pack of seemingly assorted resistors and jumper cables, as well as an aftermarked ELEGOO Arduino R3. It is at a reasonable price. | 29.99$ |
| **[ELEGOO UNO R3 Board ATmega328P with USB Cable(Arduino-Compatible) for Arduino](https://www.amazon.ca/dp/B01EWOE0UU)** | Standalone version of the Basic Starter Kit. Cheaper, but buying jumper cables and assorted resistors separately comes out to being more expensive than the former option. | 21.99$ |
| **[UNO R3 Starter Kit – 40PCS Electric Circuit & Electronics Learning Kit, UNO R3 Compatible Board with Breadboard, Sensors, RFID, Motors & Components](https://www.amazon.ca/UNO-Starter-Kit-Electronics-Compatible/dp/B0GMV21S6J)** | Includes an official Arduino R3 board. I was considering this option as I believed it included a set of capacitors, but was mistaken. Includes a set of many other useful sensors, though not relevant to this project. | 39.99$ |
I decided on the Basic Starter Kit for now, as the extra components could prove especially useful.

3: Resistor Set
	These will be bought to not rely on the board kit's resistor set - some of the items do not label the resistances and vary at each image. They also, to my knowledge, don't include anything even near the 50k Ohm range which I used for testing in TinkerCAD. I decided to buy sets of 10, as resistors can trip, and I would like more to be cautious. Unit prices also become cheaper at 10 units for DigiKey products. 

| Resistor Set | Justification | Cost/unit (CAD) |
| --- | --- | --- |
| **[DigiKey CF18JT47K0CT-ND](https://www.digikey.ca/en/products/detail/stackpole-electronics-inc/CF18JT47K0/1741721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)** (10) | This item is a 47k Ohm resistor, which is apt for my use case, as my TinkerCAD model was represented with 50k Ohm. It is also rather inexpensive per unit. rated at 0.125W | 0.036$ |
| **[DigiKey TC33X-2-104E](https://www.digikey.ca/en/products/detail/bourns-inc/TC33X-2-104E/612859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)** (10) | This is not a resistor, but rather, a 100k Ohm trimmer. This means I can adjust the resistance and set it to what I want using the multimeter and screwdriver. However, this comes with different ways of calculating uncertainty. Tolerances very high at 25%, rated at 0.15W. It's also 1 turn only, making it hard to adjust precise resistance. It is also not insulated by any means, therefore dust and feedback capacitance, as well as acoustic effects impact its effective resistance. | 0.36$ |
| **[Resistor 47k Ohm 1/4 Watt 5% Carbon Film: 47kohm 1/4W](https://be-electronics.com/products/resistor-47k-ohm-1-4-watt-5-carbon-film-47kohm-1-4w?variant=47099826733292)** (10) | This is a fixed 47k Ohm resistor sourced domestically from another website. rated at 0.25W. | 0.22$ |
| **[Vishay Spectrol 64X104 Trimmer Potentiometer 100k Ohm 0.5 Watt 25 Turn, PCB Mount Trimpot, Side Adjustment *CLEARANCE*](https://be-electronics.com/products/vishay-spectrol-64x104-trimmer-potentiometer-100k-ohm-0-5-watt-25-turn-pcb-mount-trimpot-side-adjustment-clearance)** (10) | This is also a trimmer, but sourced in Canada. It is much more expensive yet rated at 0.5W. It is to note that this is a closed, 25 turn trimmer, meaning that external variation is minimized and fine tuning is easier. | 1.69$ |
| **[uxcell 10Piece 3296W-104 100K Ohm Trimmer Pot Cermet Potentiometer \| Variable Resistors](https://www.amazon.ca/gp/product/B00D2JRALS)** (Amazon) | Cheaper closed 25 turn trimmer set, rated at 0.5W. | 1.25$ |

I've realized that wattage doesn't particularly matter much for our circuit's application, as the Arduino R3 takes in 5V from the USB and at 57k Ohm, by $$P = V^2/R$$ our power in the circuit should be around, at most, 4.38596e-4 W, which is below what any of these resistors are rated for.
I therefore decided on the Amazon trimmer, so we could experiment with a greater range of many different capacitances rather than one fixed number, while being sure that external inaccuracies are mitigated.

4: Capacitor Set
It is to be known that in our preliminary Tinkercad testing, a greater capacitance means that the amplification is smaller, so the circuit operated on 100pF capacitors. In a real world application, I also know I need a 

| Capacitor Set | Justification | Cost (CAD) | |
| --- | --- | --- | --- |
| **[10x10PCS 1KV High Voltage Ceramic Capacitor Kit \| 100pF 220pF 330pF 470pF 1nF 2.2nF 3.3nF 4.7nF 10nF 22nF](https://www.amazon.ca/gp/product/B0C5SKHXYD)** | Includes a wide variety of different capacitances, allowing me to tweak the circuit to a degree further than what I have theoretically simulated on the Tinkercad website. | 10.99$ | |
| **[300pcs 15Values High Voltage Ceramic Disc Capacitor Assortment Kit (1KV 2KV and 3KV) (Capacitor Range : 0.1nF~22nF)](https://www.amazon.ca/XLX-15Values-Voltage-Capacitor-Assortment/dp/B01M3W0SW1)** | Includes an even greater variety, yet comes at a slightly higher cost. | 14.99$ | | 

DigiKey sold only individual capacitors, limiting experimentation, which seemed to be, at the cheapest, 4$ per unit, which was far too expensive to even consider. I decided on the first option as it allows for the same range of testing as the other at a lower price point.

5: Photodiode

| Photodiode | Justification | Cost/unit (CAD) |
| --- | --- | --- |
| **[Digikey BPW34](https://www.digikey.ca/en/products/detail/ams-osram-ag/BPW34/607274)** | This photodiode is rated for the correct spectral range for this project (~400-1100nm). It is also a common, versatile pick for a photodiode. Unfortunately, the standard lead time is listed at 14 weeks. Cheaper. Ships from Canada, shipping time is unknown (claimed 1-3 days) | 2.89$ |
| **[Amazon BPW34](https://www.amazon.ca/Photodiode-BPW34-BPW34S-Silicon-Sensitivity/dp/B0F4CNXCMX) (5 pack)** | Same photodiode. Slightly more expensive yet shipping time guaranteed (~2-3 days) unit quantity is also rather high for my needs - ideally, having 2-3 as to have spares would be ideal | ~3.07$ |
I decided to buy two of the Digikey BPW34.

6: Op-Amp
I will probably not buy 10 of these, as I don't believe I will be advantaged by purchasing such a quantity given the cost of the product. I reason that 3 will be okay for my use case, as I would have 2 backups - just in case.

| Amplifier | Justification | Cost (CAD) |
| --- | --- | --- |
| **[IC 741CP - DigiKey, 296-11107-5](https://www.digikey.ca/en/products/detail/texas-instruments/UA741CP/382197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)** | The IC 741 is the op-amp which was used as a template in Tinkercad, at seems to be a rather widespread amplifier option. However, in the real world, it seems to run on dual supply from +-5V to +-15V whereas this Arduino circuit operates on a single 5V supply, which is unoptimal. | 1.02$ |
| **[TLV2372IP - DigiKey 296-12219-5-ND](https://www.digikey.ca/en/products/detail/texas-instruments/TLV2372IP/413506)** | Single supply operation from 2.7-16V. More expensive yet optimized for my use case. Broad range of voltages. Requires rewiring of the Tinkercad circuit. | 3.33$ |
| **[OP341UA - DigiKey 296-43421-5-ND](https://www.digikey.ca/en/products/detail/texas-instruments/OPA341UA/416723)** | Single supply operation from 2.5-5.5V Most expensive option. Requires rewiring of the Tinkercad circuit. | 6.84$ |
| **[MCP601-I/P - DigiKey MCP601-I/P-ND](https://www.digikey.ca/en/products/detail/microchip-technology/MCP601-I-P/305930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)** | Single supply operation from 2.7-6V. Cheapest option, all used pins match | 0.98$ |
 I have decided in favor of the MCP601-I/P as it fits the exact layout that my circuit is inherently designed for. The other op-amps need pins changed.

7: Micrometer

| Micrometer | Justification | Price (CAD) |
| --- | --- | --- |
| **[Electronic Digital Caliper, LCD 0 to 6 inch inch/mm Conversion, Automatic Shutdown Function, White/Black](https://www.amazon.ca/gp/product/B08ZNQRB39)** | This isn't a micrometer. Caliper's range is of 150+-0.2mm. Digital. It uses the metric system, which is preferred as that is what I am more familiar with (and what everything else in the circuit uses) | 10.99$ |
| **[Spurtar Vernier Caliper Measuring Tool 6 inch/150mm, Non Digital Calipers \| 0.001"/0.02mm High Precision, Durable Micrometer, Measuring Tool, Dual Imperialand Metric Scale](https://www.amazon.ca/dp/B074HZ8S21)** | This isn't a micrometer. More expensive, and mechanical. This caliper's range is of 150+-0.02mm, which is much more precise. Its build quality also appears to be higher. | 17.98$ (33% off) |
| **[Inside Micrometer, 0-13mm Micrometer Flat/Ball Head](https://www.amazon.ca/Micrometer-Fine-Tuning-Various-Accuracy-Instruments/dp/B083KHFKZ6)** | 13+-0.01mm precision micrometer. Also doesn't include the c frame, which is useful for my applications. Range is rather limited, though this is not an issue. | 18.47$ |
| **[HDLNKAK Outside Micrometer 0-1",0.0001" Precision Graduation Micrometer Set \| Ultra-Precision Standard Micrometer Carbide Tipped Measuring Tool with Case](https://www.amazon.ca/dp/B0CF917TB5)** | 1"+-0.0001' precision micrometer. More expensive, and The c frame needs to be removed. Additionally, it makes use of the imperial system. | 19.99$ |
Considering every product, I have decided on the third listing, as a micrometer head is easier to create a 3d printed mount for than the other options. It also offers the highest precision using the metric system out of these products.

8: Lens
According to previous sources, [10] DVD drives contain concave and convex lenses which could work for my Michaelson interferometer. According to me, true optical concave lenses of relatively short focal length (<20mm) are not very readily available at a reasonable price considering the budget. Here are some options I found:

| Lens | Justification | Price (CAD) |
| --- | --- | --- |
| **[Tangxi 30X Jewelry Magnifier, Professional Optical Magnifier Glasses, 30X Magnifying Lens](https://www.amazon.ca/gp/product/B07X49J7PM)** | 30X divergent magnifying lens which seems solid in material. However, unknown exact focal length. It is also not purpose built and therefore could be very unoptimal. | 13.48$ |
| **[PATIKIL 12 Pcs Convex Lens, 12mm OD 17mm Focal Length Magnifier Lens Optical Lenses Borosilicate Magnifying Glass Flat Convex](https://www.amazon.ca/dp/B0G3PBDDG1)** | 17mm focal length, small convex lens (perhaps too small). | 10.99$ |
| **[KIMISS 4X Achromatic Objective Lens for Biological Microscope 160/0.17 High-Quality Achromatic Objectives for Clear Imaging in Scientific Research](https://www.amazon.ca/KIMISS-Achromatic-Biological-Microscope-High-Quality/dp/B0D4PCV9CC)** | Achromatic objective lenses work much better for my application. This 4X enlargement lens has a longer focal length than the other options | 14.17$ |
| **[DM-WJ002 185 Biological Microscope Objective Lens Silver 10X Achromatic Objectives Lens 160/0.17](https://www.amazon.ca/gp/product/B082P3P953)** | Same as 3rd option, but with 10x enlargement, and slightly more expensive. | 18.83$ |
Considering the final two products, I decided to opt for the 10X achromative objective lens as the shorter focal length will contribute to making my setup more compact (surface which the fringes are observed on is closer to the rest of the system).

9: Mechanical Breadboard
This WILL come back later, as I did not do a thorough comparaison. For now, I decided on:

| Sheet | Justification | Cost (CAD) |
| --- | --- | --- |
| **[Basswood Sheets 12 Pack, 12"x12"x1/16" Thin Unfinished Plywood](https://www.amazon.ca/gp/product/B0D4CD82S3)** | This plywood sheet shouldn't deform all is easy to drill holes in, comparing to previously considered metal sheet. However, it warps to humidity/thermal expansion. | 29.99 |

10: Magnetostriction Rod

| Rod | Justification | Cost (CAD) |
| --- | --- | --- |
| **[SHONAN Nickel Anode- 7.87"x0.3"(Diameter) Nickle Anode, Pure Nickel Bar, Nickel Rod](https://www.amazon.ca/gp/product/B083LJWQYG)** | Quick shipping time. 8mm diameter below the dimensions of my mirror (12.7mm). 99.6% rated | 23.10$ |
| **[TEN-HIGH Nickel Anode Pure Nickel Bar 3.94" x 0.39", 99.6% Nickel Rods](https://www.amazon.ca/dp/B0BW47Q79T)** | Half the length of the other rod, but considerably more expensive. The diameter is larger at 10mm. | 58.44$ |
I decided to opt for the first item.
11: Solenoid Wire

| Wire | Justification | Cost (CAD) |
| --- | --- | --- |
| **[23109-18GA Copper Wire 25FT 14LB](https://www.amazon.ca/gp/product/B000H5OL30)** | This should be enough copper wire for a solenoid with 30V running through it to create a proper magnetic field, strong enough for magnetostriction. Cheap. | 9.99$ |

---

2026-08-06 
	Goal: Catch up on documentation - while I have made very rough documentation in the past few days on my phone, I want to further it in a way which can be shown on my journal in a more concrete way. I am also running late on it and would like to update it before I continue on to do new things.
	Time spent: 2h1m (1h0min logged on Stardance)
	Today, I learnt that I had incorrectly bought UV Enhanced versions of the mirrors while NON UV versions existed and had the same shipping conditions and price, yet reflectance at almost 95%. This would give me the same level of precision yet higher efficiency, making it slightly easier to calibrate. However, I figured that this would not be too significant for my testing, as the TIA photodiode circuit I have employed can simply adjust to this lower power with a bigger resistor.
	I am also questioning my choice for the board. The **basswood breadboard** I previously chose may be easy to drill, but basswood can be flexed and deform quite a bit, which may be problematic for my experimentation. This is why I had originally set out to find an aluminium pre drilled board. Here are the options I considered today:

---
Firstly, the criteria for which I choose the material had to be identified. I wanted something which, ideally, was:
-Easy to work with
-Doesn't deform under stress in any meaningful way
-Fits within allocated budget (<30$)
-Thickness >=10mm
-Board dimensions > 250x250mm
-Ships to Canada in under 7 business days

| Material | Explanation | Cost |
| --- | --- | --- |
| **[Basswood Sheets 12 Pack, 12"x12"x1/16" Thin Unfinished Plywood](https://www.amazon.ca/gp/product/B0D4CD82S3)** | 12 pack of 12x12" 1/16" thickness boards is frankly, too thin. This plywood sheet shouldn't deform all is easy to drill holes in, comparing to previously considered metal sheet. However, it is very susceptible to humidity/thermal expansion. | 29.99$ |
| **[Performore Expanded PVC Sheet – Lightweight Rigid Foam – 3mm (1/8 inch) – 12 x 12 inches – Black](https://www.amazon.ca/Expanded-PVC-Sheet-Lightweight-Displays/dp/B08PC743GY)** | 2 pack of 12x12' 1/8' thickness - still very thin. A solid PVC sheet will not deform as much as wood under load and can be screwed cleanly along any surface point. | 25.34$ |
| **[Genmitsu 3040 MDF Spoilboard, Work with 3040 Y-Axis Extension Kit, 3018 CNC Upgraded Accessories Compatible with Most 3018, 3018-PRO/ 3018-MX3, 30 x 36 x 1.5cm (11.8'' x 14.1'' x 0.6'')](https://www.amazon.ca/Genmitsu-Spoilboard-Extension-Accessories-Compatible/dp/B08VN6HXPD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)** | 30x36cm 1.5cm thickness size is fair. Comes with precise, pre threaded M5 screw holes and locknuts, along with some other items as a kit. Technically designed as a CNC spoilboard, and less material in volume. | 29.74$ |
| **[DEAYOU 10 Pack 11" x 14" MDF Wood Boards for Crafts, 1/4" Thick Medium Density Fiberboard, Unfinished Art Chipboard Sheets, Blank Wooden Hardboard Panels](https://www.amazon.ca/DEAYOU-Fiberboard-Unfinished-Chipboard-Hardboard/dp/B0F6N2MY9L)** | 10 pack of 11x14' 1/4' thickness boards. This mdf sheet is easy to drill yet, over twice as thin as the 3rd option and therefore much more susceptible to humidity/thermal expansion. | 27.99$ |

With these different boards in consideration, I decided on the Genmitsu 3040 MDF Spoilboard, as the pre-drilled holes seem to be extremely useful for my use case, and almost replicate actual, much more expensive optical boards. 

**Now, the materials list was finally done.**

2026-08-07\
	 Goal: Finish catching up on documentation.\
	 Time spent: 1h0min (37min logged on Stardance)\
	 Activities: Filling in this document with various comparaisons of different items. \
	Today's global analysis of every item primarily gave me a full global understanding of every part of the project, as I had to now give explanations to the disadvantages and advantages of every option, for every component. Previously, I had justified the components only very briefly, so this gave me a clear picture as to ***what** I am doing, and **how** I will do it. Much of my time was spent indexing all the items, embedding them on this document as a clear demonstration of product research.

2026-08-08\
	Goal: Finish listing components, make final design choices\
	Time spent: 4h37min ( logged on Stardance)\
	Activities: Continuing the item comparaisons for every product, and creating a rough perspective sketch of every component of the Michaelson Interferometer - the overarching system - in action. \
	
	Decisions\
	 D-010: I decided to rethink how the system works- the mirror not attached to the magnetostriction subsystem will be attached to the moving micrometer and move during the laser wavelength experiment.\

Previously, I wrongly designed the system to have two fixed mirrors and a photodiode which moves along, perpendicularly to the laser image expanded by the lens, using the photodiode, thinking the math would be the exact same (Spoiler alert - its not). The mirror movement makes the fringes/interference patterns change predictably, but moving along the fringes mechanically along a spherically expanded image is much more complicated to calculate. The equation for determining wavelength with a perpendicularly moving photodiode with an expanded image can be found from Young's Double Slit experiment:\
$$y =  \frac{\lambda \cdot D} d$$ where D is the distance from the source focal plane to the photodiode, d is the separation between virtual sources (what stretches/compresses fringe pattern) and y is the width of one fringe, determined by dividing the distance travelled by the photodiode by the number of peaks (fringes) measured, giving the equation:\
$$ y = \frac{ \Delta x} N $$ (delta x is the distance travelled and N is the number of fringes). [11] Then, we can substitute this into the former equation and isolate for the wavelength, giving the equation\
$$\lambda = \frac{\Delta x \cdot d} {N \cdot D} $$ we are able to measure the change in distance of the photodiode, the distance from focal plane to the photodiode and the number of peaks/fringes. However, there is not a way to find or cancel out the separation of virtual sources, d. Determining this value according to our system's alignment would require using a laser with a known, precise pre-determined wavelength, which goes against the premise of using a DVD drive. It is also to be known that micrometer level changes in alignment of the mirror, laser or beamsplitter can alter this value to the point where measuring wavelength becomes unfeasible using this concept without engineering methods to align each component with maximal precision. In comparaison, the equation for finding the wavelength from fringe signal with a moving mirror is, as stated earlier,\
$$\lambda = \frac{2d}{\Delta N}$$
(d is the distance between fringes and ΔN is the number of fringes observed) it not only has less variables needed to precisely keep track of, but we can determine all these values without solving based off a known wavelength value. Therefore, it makes much more sense to use this system, where both mirrors can move - one mechanically, the other based off magnetostriction - for our testing. \

2026-08-09\
	Goal: Ordering components, finishing up documentation on said components\
	Time spent: 3h9min (1h5min logged on Stardance)\
	Activities: Finally catching up to progress in the document! Ordering the rest of the online components which I cannot easily source physically. I also verified that the logic for the above equations made sense.\
	
	Decisions\
	D-011: I decided to change the resistor I was considering from the Digikey to the Amazon trimmer option. This is because spending more money to have insulation offers protection to external factors such as dust, sound and parasitic feedback capacitance, making sure that my TIA circuit stays exactly how I want it to be. \

**Purchase cost so far: 324.09 CAD** across DigiKey, Amazon and THORLabs. This is good! There are 25.91$ left for extra materials, such as the missing m5 screws, or if I ever need more filament.

2026-08-10\
	Goal: Creating a proper technical drawing for the next devlog to show that the design step of my project is complete.\
	Time spent: 3h06min\
	Activities: I spent much of my time ensuring I got every single measurement precisely by comparing to reference sizes I got through product listings, and compiling them onto a top view technical drawing. Additionally, I used this to begin designing rough mounting brackets I will need to align every part in the interferometer, by knowing where the screws will be. \
	
	Decisions\
	D-012: I decided to include both the screw adjustment system AND the micrometer in the mirror opposite to the diode. This is so I have a way to firmly adjust the mirror in case it is slightly off in terms of angle whilst keeping the precise translation that the micrometer head offers. I decided to put the head on a set of metal rods which act as rails, helping in stability to guide the mirror forward.\
	D-013: I decided to lengthen the supports for the magnetostriction mirror beyond the boundaries of the board. This is because the nickel rod is 20cm long, and therefore, keeping it stable along its length is crucial to mirror alignment.\

2026-08-11\
	Goal: Create a proper bill of materials, begin CAD designs for components of known dimension.\
	Time spent: 1h09min (44min logged on Stardance)\
	Activities: creation of BOM.csv (in Github), weighing options for CAD modeling software
	- Unexpected thing today - The ThorLABS aluminum UV protected mirrors' shipping failed, cancelling the purchase. (card from different country, exporting from Germany to Canada) and thus we were able to twitch to the silver mirror, which us shipping cost went back to normal for. Therefore, the transmitted power of the mirrors goes up from 82-83% to 95-97%! Parts remain unordered as of now, however.\
	
	Decisions\
	D-014: Switching to the silver version of the mirror \
	D-015:  Using paper as screen (grid paper) is the best option. Not only does it save money, but it also offers a coordinate-like grid to properly center, align and calibrate the interferometer. It also offers great laser fringe clarity with respect to some other alternatives I considered, such as MDF, cardboard or PVC.
	
	D-016: CAD work will be done in Tinkercad's 3D modeling suite, as to make it easier and faster to block out ready-to-print designs than just about anywhere else, with good topology.

Traveling for a few days will make it difficult to journal in the coming days. However, I will try.

2026-08-12\
	Goal: Sort mirror situation\
	Time spent: 1h06min (N/A logging)
	Activities: Back and forth emails between us and customer service - search for alternative options.\
	- Thorlabs mirrors ordered again, this time, the silver ones, and declined to ship once again - however, this time, it was the silver mirrors. The supplier said we needed to supply from Germany. However, the shipping cost from Germany amounted to 81.55 EUR (130.91$ CAD) which is higher than the cost of the mirrors themselves. While technically not in my budget costs, this would hurt my wallet quite a bit... therefore, I began my search for alternative mirror options. I primarily searched on Amazon, as this website offers a much more reliable shipping framework, making it easier to source. Instead of searching purely for optical grade mirrors, I expanded my search to anything which could fit the needs of a precision mirror.

---

| Product | Description | Cost (CAD) |
| --- | --- | --- |
| **[Diameter 114 mm Focal Length 900mm Newtonian Reflector Mirror for Astronomical (D114F900JP)](https://www.amazon.ca/gp/product/B096F28YR6)** | 1/10λ rated surface accuracy and 92% reflectance @400-950nm. However. it is not a flat mirror (900mm focal length) and massive for my project, at 11.4 centimetres in diameter, which will make building mounts extremely tricky. | 71.48$ |
| **[20mm Silicon(Si) Laser Reflection Mirrors for CO2 Laser Cutter Engraver/Cutting Engraving Machine, 3 Pcs Dia. 20mm /0.79"](https://www.amazon.ca/gp/product/B08R88TZMJ)** | CO2 Laser Cutter Reflection Mirror. At 650nm, the listed uncertainty can be calculated to be about 0.77λ of surface flatness - this is because they are intended for 10.6 micrometer light, and work amazingly in this scenario, but not as much for shorter wavelengths such as the ones we are experimenting with. Other metal options are available but have higher uncertainties. | 55.55$ (8.45$ as of 8/17/2026! wow!) |
| **[Alpha Nanotech Silica Wafers (Dry Oxide Only; Sizes: 6'', 4'', 2'', Oxide Thickness: 200 nm) (2 inches, Qty: 1 pc)](https://www.amazon.ca/gp/product/B07RFF6XWN)** | This is not listed as a mirror, but rather, as a silica wafer. The imprecision translates to about 1/6λ at 650nm, which is great. However, 2 inches of diameter would still require slightly redesigning the mounts. Additionally, the reflectance, at 40%, is rather poor, and could prove to be even lower, meaning lots of power would be lost. This would mean adjusting to higher resistances in the TIA circuit to get the same outputs, which we would do by tuning speed of movement of the mirrors much more finely. | 45.00$ |
| **[2PCS Small Size Front Surface Mirrors High Reflectivity for Projectors Scanners Precision Optical Instrument DIY Accessories(10x10mm,2mm)](https://www.amazon.ca/Reflectivity-Projectors-Precision-Instrument-Accessories/dp/B0GB9C66T6)** | First surface mirror which comes in a wide variety of sizes. 97% reflectance (at wavelength unknown) and lack of overall information. Arrives August 25-September 1st, which would absolutely NOT leave enough time to complete the project by September 1st. However, affordable. | 24.65$ |

``Decisions
`D-017: ended up **NOT** choosing any for now, as "I am still confident that the ThorLABS mirrors will arrive without too many issues." (Edit 08/17/2026: this aged well...) 
	- The best backup option, as of now, is the Silica wafer, as it offers the level of precision I would need to perform magnetostriction experiments and is possible to use with more resistance in the TIA circuit. If not, looking back at the Edmunds mirrors and going ever so slightly overbudget doesn't seem like a bad option now...

2026-08-13\
	Goal: Confirm if ThorLABS mirrors are arriving...\
	Activities: Communication with mirror supplier.\
	Time spent: N/A\
	- Today, we received a clarification email saying that shipping the silver mirrors from the US, rather than Germany, was possible. This would cut down costs from the aforementioned ridiculous European import price to the earlier US shipping value (equivalent to 49.40 CAD). We replied saying we would like this as an option - after some more payment difficulties, they invited us to directly call their support line. This will be a task for tommorow.\

2026-08-14\
	Goal: Confirm if ThorLABS mirrors are arriving...\
	Activities: Calling ThorLABS\
	Time spent: N/A\
	- At last, it seemed there was a glimmer of hope for sourcing these high precision silver mirrors. When I called ThorLABS' service department, they told us the order had once again not been processed - we agreed to wire transfer directly. This is good, as it should solve issues regarding inconsistency with billing, shipping and card adresses, allowing for a smoother ordering experience for these mirrors.\

2026-08-15\
	Goal: Restart with project properly to prepare for building\
	Time spent: N/A\
	Activities: Unboxing all parts to ensure that they have properly arrived. \
	- Today, I got home and all but four components were at my doorstep. I opened and checked every component to ensure the right materials had arrived. However, three of the items from Amazon had been cancelled. These were the **Lens** (**[DM-WJ002 185 Biological Microscope Objective Lens Silver 10X Achromatic Objectives Lens 160/0.17](https://www.amazon.ca/gp/product/B082P3P953)**), the **Nickel Rod ([SHONAN Nickel Anode- 7.87"x0.3"(Diameter) Nickle Anode, Pure Nickel Bar, Nickel Rod](https://www.amazon.ca/gp/product/B083LJWQYG))** and the **Beamsplitter ([Beam Splitter Cube, Optical Glass Dichroic Prism Ratio 50:50 Spectrome Sicence](https://www.amazon.ca/gp/product/B0B34FK2GF)**). I reordered these components to no issue. However, nothing more was heard of from the ThorLABS support team.
	this is where all the images go !!!!!

2026-08-16
	Activities: Disassembling DVD drive to procure laser diode, CAD design work for mounting system
	Time: 3h32min (2h09min recorded on Stardance)
	`Decisions\`
	`D-018: I will favor the usages of rounded, filleted edges in my design. This is since fillets offer better stress concentration relief and allow to save some material for the many different iterations which are likely to come.`
	`D-019: I enlarged the beam spliter design from 24x24mm in width to. This is to ensure the beam splitter remains solid. To make the component easier to print, I split it into two different pieces, which are designed to be firmly connected using two M3 screws.`
	`D-20: The laser diode mount will be designed slightly larger to encompass the metal casing it is placed within, as I am having trouble isolating it. This also required the center level of every other structural bracket to be raised to 22mm, as opposed to 12mm as previously.`

---
# CAD Design Process
2026-08-16\
1) **Micrometer Mirror Mount (MMM)**
I started by making the micrometer mount first. I largely based myself off the sized already present in my on-paper design initially. I measured some parts of my real micrometer head using a 30cm ruler, then, cross referenced it with blueprints of similar micrometer heads available on **[MiSUMi](https://us.misumi-ec.com/vona2/detail/223006520381/?seriesCode=223006520381&tab=catalog&Page=1)** (on this page.) The 1009-350 very closely matches the design I found on Amazon, so I used its exact measurements to my Tinkercad model off of. I believed by model was 5mm longer, so initially adjusted the design to this difference, however, upon looking back, it appears to be about the same length, too. This will be tested once component 3D printing begins. When making the supports, I stepped away from the original designs just a bit - instead of adding a second micrometer mounting I decided to only extend the top mounting downwards to support the micrometer, saving print material and improving stability of the micrometer. when making the mirror adjustment system, I decided o space the M3 screws further out than previously listed. While the mounting rods didn't directly have a specified spacing away from the screws, they now sit 35mm away from the central axis and 30mm above the ground. The mirror adjustment plates also did not have a specified length - they are now 90mm long (and 41mm tall.) The top micrometer mounting bracket plate is now 145.5mm instead of 145mm. I also added a support to the mirror adjustment plate to guide the mirror into the system.
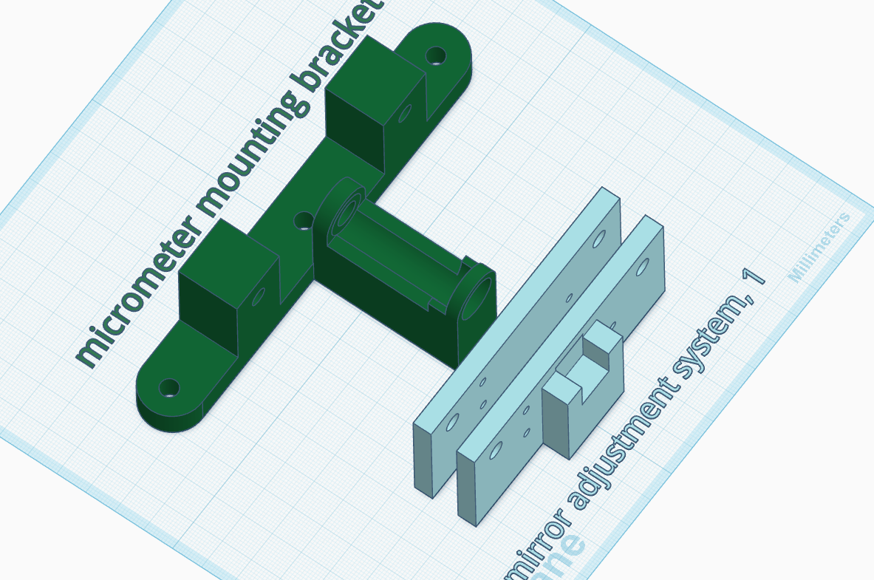
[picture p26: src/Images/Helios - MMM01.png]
Helios - MMM01.png|401

Fig 1. - Tinkercad screenshot of micrometer and mirror 1 mounting systems as of 2026/08/17.
2) **Beamsplitter Mount (BSM)**
I had to go back to the drawing board when it comes to this mount. In my technical drawing, the 20x20mm beamsplitter would fit in a 24x24mm holder, meaning the outer walls were 4mm thick - there were also only two outer walls. In this iteration, I made the walls to be 7mm thick, giving a 34x34mm footprint. I also went back to the drawing board regarding the idea that this needed to be a single piece - Separating into two pieces, the beamsplitter bracket and beamsplitter mount, allows me to avoid complications with 90 degree upright angles while 3D printing, ensuring ease of production, while still being remaining to the original technical drawing model. I also added a circular 6mm radius to the outside of the M5 screws in the bracket, as this will slightly save on printing material while keeping the screws firmly guided, and the bracket firmly locked to the plate. I added two smaller 3mm holes to firmly lock the mount and bracket together, too, using either M3 screws or even wooden dowel pins.
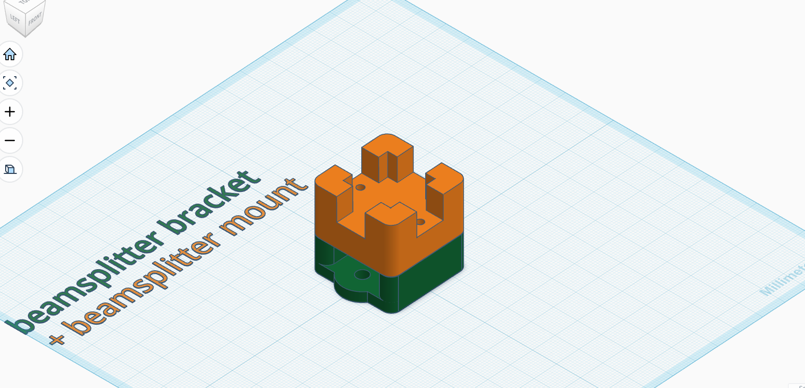
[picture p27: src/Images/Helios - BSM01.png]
Helios - BSM01.png

Fig 1. - Tinkercad screenshot of beamsplitter mounting system as of 2026/08/17.
3) **Diode Mount (LDM)**
Due to my previous efforts to isolate the laser diode from it's casing having failed yesterday, I decided to make a part which would incorporate the casing, too. Since the diode would therefore be raised 22mm up - higher than any other component - the standard for height required raising every other mounting platform to account for this difference. This mount is also slightly changed from its technical drawing, as the top-down footprint stayed about the same, but the way the laser diode is incorporated changed quite significantly. I make a hole in the bracket to serve as a guide for the metal component. To hold it in place more firmly, I added an M3 screw hole.
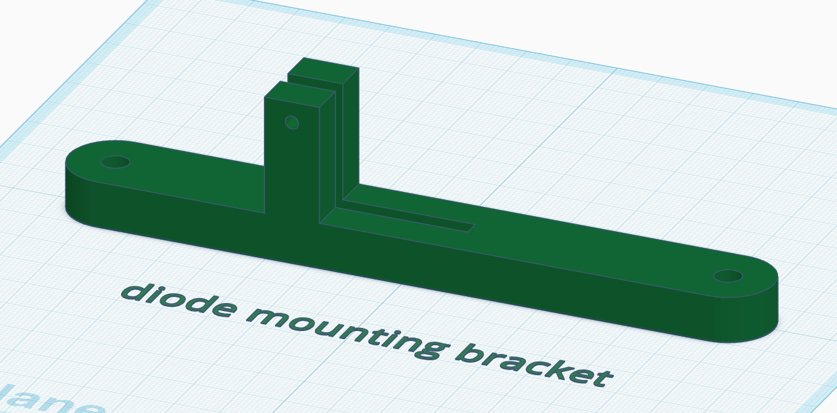
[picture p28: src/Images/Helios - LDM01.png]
Helios - LDM01.png

Fig 1. - Tinkercad screenshot of diode mounting bracket as of 2026/08/17.
4) **Lens Mount (LMB)**
My lens has not actually arrived yet, therefore, I used Amazon size specifications and identified the lens to be a generic DM-WJ002 10X achromatic microscope objective. I searched online yet found no matching CAD model available. To approximate, I used the **[RMS10X10X Olympus Plan Achromat Objective, 0.25 NA, 10.6 mm WD](https://www.thorlabs.com/item/RMS10X)** STEP file from ThorLABS (granted, a much more expensive lens option) and converted it to a .obj file. Despite being broken, it was still meaningful insight on how to set up my actual lens. Eventually, a fixture system will be added, as I am reconsidering the M3 screw hole setup I have used in the diode mount. 
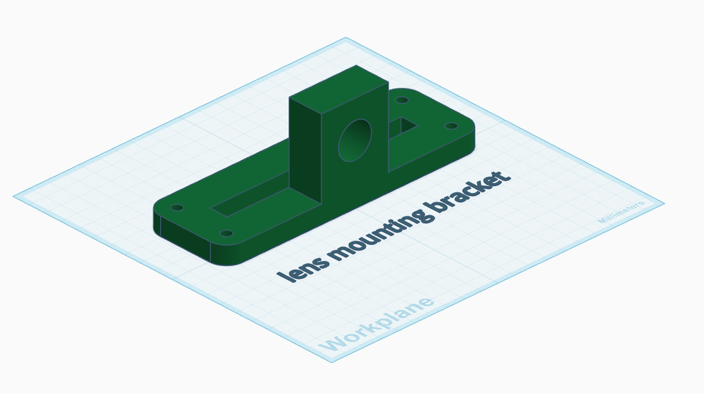
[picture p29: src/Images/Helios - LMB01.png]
Helios - LMB01.png

Fig 1. - Tinkercad screenshot of lens mounting bracket as of 2026/08/17.

2026-08-17
	Goal: Finish CAD design elements.\
	Time spent: 2h23min (logged on Stardance)
	Activities: continuing CAD modeling, compiling and updating documentation from during and after the break\
	`Decisions`
	`D-021: I decided to keep the out of board bracket design in the solenoid brackets. This is as the nickel rod is very long, and needs to be adjusted to the center of mass to not cause any problems involving acoustic vibration.` 
	In the evening, we received an email from ThorLABS stating that the specific mirror I had purchased, the **[PFSQ05-03-P01](https://www.thorlabs.com/item/PFSQ05-03-P01)** was only in stock overseas. Disregarding the fact that it had not been listed as such in days past, I set out to once again review the list of mirror alternatives. As I did so, I spotted that the **[25mm Silicon(Si) Laser Reflection Mirrors for CO2 Laser Cutter Engraver/Cutting Engraving Machine, 3 Pcs Dia. 25mm /0.98"](https://www.amazon.ca/gp/product/B08R88VRW1)** were set at an 85% discount, and were now selling for 8.45$. I, therefore, rushed to order a set of these mirrors as a backup option, in case the ThorLABS mirrors ended up not arriving. These mirrors, at 650nm, have about a 0.77 λ surface flatness. While not being exactly designed for the wavelengths I need (CO2 laser cutters use wavelengths of about 10.6 micrometers), it was way too good of a deal to simply pass up. These are set to ship on 2026-08-19.

---

# CAD Design (contd.)

5) **Solenoid Mirror Mount (SMM)**
This is possibly the most complex part of the entire mounting system. I began by modeling the solenoid cover around a to-scale nickel rod - since this item hasn't arrived yet, I can't measure true scale, so I had to use Amazon listing measurements as a reference. This component is likely the most unchanged aspect of the technical drawing. I then built two, smaller separated support brackets as opposed to what is illustrated in the technical drawing -  this is to ensure the solenoid cover and over components remain leveled with respect to the center of mass of the overall system (solenoid, cover, nickel rod, mirror mounting plates). Center of mass is a concept which I had to heavily explore through this system. A balanced center of mass keeps the system from tipping in any way while dampening any surrounding acoustic vibration, keeping everything firmly in place. Therefore, I explored several different mirror mounting designs.\
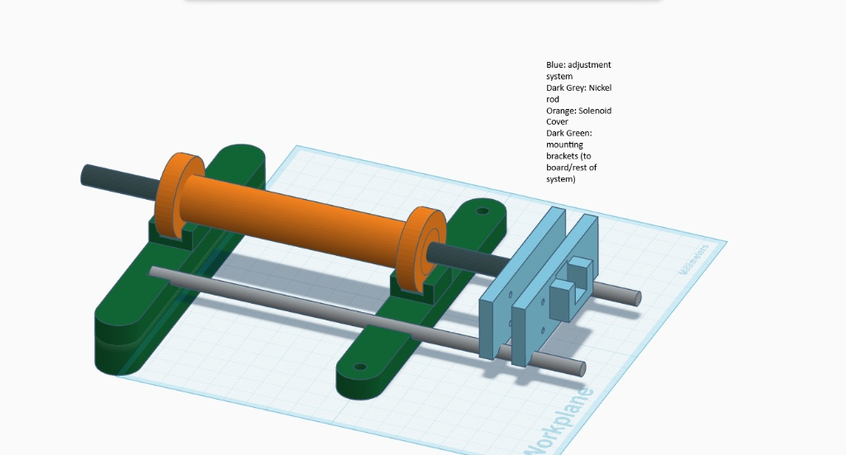
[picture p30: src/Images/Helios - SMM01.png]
Helios - SMM01.png

This was the first iteration - a rod rail system with guides in the mount and brackets which would force translation forward. The problem is that the adjustment screws would throw the plates off course in rather difficult to predict ways, and the friction between the PETG-CF and material used for the rails would lead to the uneven surfaces of both materials throwing the mirror off course ever so slightly. When measuring micrometers of change, this is not ideal for measuring the effects of magnetostriction.\
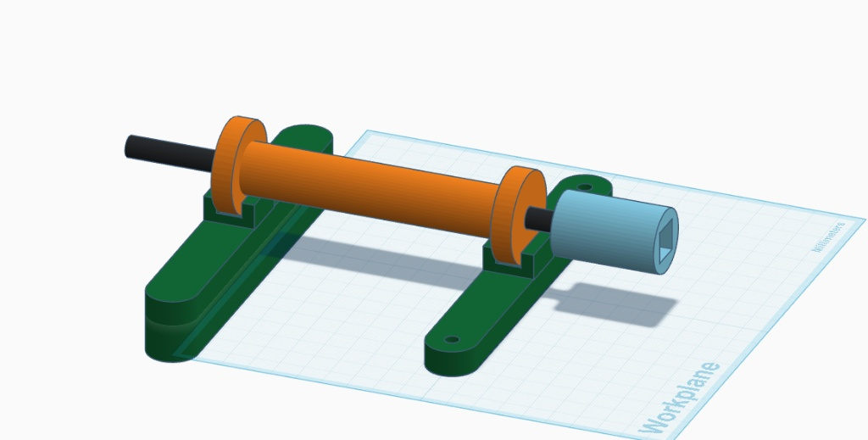
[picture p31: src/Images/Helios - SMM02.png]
Helios - SMM02.png

This was the second iteration - a non-adjustable mirror mount with a hole fitting neatly with the nickel rod, and another to place the mirror in. This was deemed to not be adjustable enough, as, even with the lack of friction, the inability to adjust the rotation of the mirror precisely was still a major downside. Then, for my third iteration, I envisioned simply gluing the mirror itself to the nickel rod. This was a better idea than the non adjustable mirror mount, saving a few grams, yet it was still not fully optimal.\
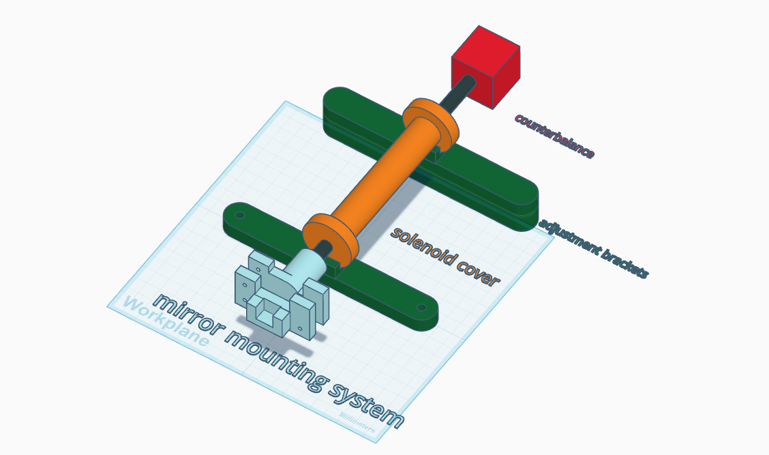
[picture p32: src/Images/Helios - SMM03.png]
Helios - SMM03.png

Here is the iteration i ended up deciding on. I re-introduced the mirror mounting plates, this time, suspended in the air, and cut off a small section of the top to save on material - while incorporating the nickel rod hole from the previous design. This gives the best of both worlds when it comes to stability and adjustability. I decided to add a fictional counterbalance, whose volume will be determined once the mirror mounting system has been properly measured. 
A way to link the adjustment brackets together would now be great., as the taller one is currently hanging, and the rest of the overall system is very sensitive to changes.

2026-08-18
	Goal: Catch up on documentation, try out 3dprinting and Arduino starter kit functionality.\
	Time spent: 3h05min (2h32min logged on Stardance)\
	Activities: Sorting out mirrors, successful experiment with Uno R3 kit and DVD drive laser diode, catching up fully on documentation.\
	- Today, we were able to call ThorLABS about the mirrors. The payment had gone through, yet, the lead time for importing the **[PFSQ05-03-P01](https://www.thorlabs.com/item/PFSQ05-03-P01)** would about 3 months, which is far too long for my project's needs. Therefore, I considered to change the order to the **[PFSQ05-03-G01](https://www.thorlabs.com/item/PFSQ05-03-G01)** , which has the same dimensions yet is coated with aluminum and performs similarly. However, this item costs more, and therefore needed another wire transfer - increasing shipping time by a matter of 5 days on top of the week expected for international shipping, which would be about August 30th. 2 days of room to work with is still far too few, so I decided that I had to switch to a product of equal or lower price. I considered the **[PFSQ05-03-M03](https://www.thorlabs.com/item/PFSQ05-03-M03)** for its equal price and gold coating. It is technically not meant for the wavelengths I need yet is shown to have 95.71% reflectance (within range of P-01 silver's 95.72%). Finally, I decided on the **[PF05-03-P01](https://www.thorlabs.com/item/PF05-03-P01)** as it is another silver mirror which would perform identically to its former square silver twin which is unavailable in the North American market. It is also of the same dimensions, yet instead, it is cylindrical, meaning I would need to slightly rework the mounts - this however costs 5.70 USD less. It is arriving August 25th. All things considered, this mirror seems like a solid purchase! Unfortunately, the failed shortly after being made, so things fell through.\
	- Upon opening the Elegoo R3 kit, I found that the resistors were already labeled from 100 to 1M Ohm. This is a pleasant surprise, as an amazon review claimed the product had less than what was advertised - it in fact had more.
	- I then further disassembled the DVD drive down to the raw laser diode, and got the Arduino to successfully power the laser diode! Great news with just a small problem - now, the collimating lens was detached, so the light expands, fast! This means I need to either re-align the DVD drive lens or restructure the design to use the 10X lens to collimate the beam of light, which would be tricky to do precisely. Nevertheless, I'm extremely happy the electronics now work! The CAD for the laser diode will need a redesign, but everything seems to be falling into place rather smoothly, for now. My goal tomorrow is to have a working full design I can submit for a funding request.

2026-08-19\
	Goal: Continue CAD modeling, test 3d printer capabilities\
	Time spent:\
	Activities: work on LDM and MMM components
	- Today, I printed an early iteration of my laser diode mount (LDM). The mounting holes were misaligned (too big), and I ignored tolerances completely, so I tried again. This time, it was better, but still slightly misaligned (too small.) Tolerance, at ~0.5mm, was still too small - on top of that, I added a triangle wedge to ensure the diode would stay in place, but it was flipped by the wrong side.. 
	- I created the acronym list to further simplify documenting parts in this project later on, making the process less verbose. I made M3 and M5 screw holes bigger in the MMM and LDM to acommodate heat inserts in the future.
	
	Decisions
	D-022: I decided that subcomponents in CAD will be named with the convention XXX.0.0, where the first three letters represent the component, the first number represents the iteration and the second number represents the indentifier for the component, based off decreasing order of size, starting from 1 (1 is the biggest dimensionned sub-component). 

I bought three new items today. Here are the items I bought and my justifications for each one. Not much comparaisons were made, as I generally simply bought the cheapest available listing on Amazon. These were the **[Glarks 7Pcs 1.5/2/2.5/3.2/4.1/5/6.6mm Soldering Tips Sets, with 1 Set Heat Set Insert Tool, 130pcs](https://www.amazon.ca/dp/B0F8GT8PH1)** heat insert kit, the **[520PCS Hex Bolts Nuts Washers Combination Kit, 304 Stainless Steel, Metric M3 M4 M5 M6 Hex Nuts and Bolts, Full Thread Mechanical Screws, 12 Commonly Used Sizes](https://www.amazon.ca/dp/B0GCRDQ8RG)** screwing set and the **[Laser Diode Module 650nm 5mw Red Diodes 2Pack(Dot)](https://www.amazon.ca/Qiaoba-Laser-Diode-Module-Diodes/dp/B07L416LV1)**

| Item | Justification | Price (CAD) |
| --- | --- | --- |
| **[Glarks 7Pcs 1.5/2/2.5/3.2/4.1/5/6.6mm Soldering Tips Sets, with 1 Set Heat Set Insert Tool, 130pcs](https://www.amazon.ca/dp/B0F8GT8PH1)** | A heat insert kit could prove very useful in finely inserting the screws in my 3D print mounts, reducing room for miniature movements due to the nature of imprecision brought on by 3D printing. | 7.43$ (70% sale, regular price: 24.99$) |
| **[520PCS Hex Bolts Nuts Washers Combination Kit, 304 Stainless Steel, Metric M3 M4 M5 M6 Hex Nuts and Bolts, Full Thread Mechanical Screws, 12 Commonly Used Sizes](https://www.amazon.ca/dp/B0GCRDQ8RG)** | Essential to the assembly of my project. Wide variety of screws enabling me to mount every component to my spoilboard in a modular manner. | 20.79$ (6% sale, regular price: 22.09$) |
| **[Laser Diode Module 650nm 5mw Red Diodes 2Pack(Dot)](https://www.amazon.ca/Qiaoba-Laser-Diode-Module-Diodes/dp/B07L416LV1)** | Backup option to the DVD drive diodes. A sure fire way to reliably test my interferometry platform with a pre-determined, known value and much easier mounting accessibility than the DVD drive laser and it's associated lens. | 8.95$ |
In total, adding these items brings my total cost to 349.15$. A little scary, as it gives almost no headroom for additional components, but I posit that this will not be of much issue, as no more components need to be bought (and hope that this isn't foreshadowing).
2026-08-20\
	Goal: start printing proper components I could use for my project\
	Time spent:\
	Activities: Today, I started off by printing the largest part of the MMM. The screws were still ever so slightly misaligned. Furthermore, the grip design for the micrometer was not firm to my liking, and the translation led to unforeseen effects. Therefore, I redesigned it by making one of the top arches locked inside the micrometer. To install, I must unscrew the micrometer handle then reinstall after the part is lodged in. I also properly aligned the screws. 3D printing the MMM should be good now (final: MMM.05.X.stl) - I also slightly redesigned the BSM (note to self: update using Lapse description!)\
	Very late in the evening, the lens has arrived. I can now make a much more precise lens mount than one based on rough approximations found online. It appears to also be 28mm along the desired mounting surface upon rough observation.
	To log my progress, I have switched to GitHub as to insert images more easily.

2026-08-21\
	Time spent: 7mins\
	Goal: print LMB\
	Activities: Small day. Today, I fixed the mounting alignment for the LMB (removed extra 2 screwholes and lengthened them to fit to the spoilboard), enlarged the laser mount to fit the lens case, and added m3 an adjustment screw on top. I published this LMB to Github (LMB01.stl). Unfortunately, the lens was NOT compatible with my mount. I found that the casing expands from the bottom to top, from a size of 28mm to 30mm - something I did not account for. \
	
2026-08-22\
	Goal: Start building actual project! (integrating components onto spoilboard)
	Activities: Drilling to enlarge MMM mounting holes and make holes in lens casing using diamond drill grinding bit. 3D CAD modeling work, 
	Time spent:
	- I spent the morning drilling into the MMM micrometer mounting hole. Despite being posted as a final version, the hole for the micrometer is actually slightly too small, and required being expanded to lodge the bottom portion of the instrument within it. In the beginning, I was using a drill and spare 1cm radius diamond drill grinding bits sourced from the online website Temu a rather long time ago. Unfortunately, I was unable to find exactly which set I had used for this reason. It also was wobbling inside of the drill as it was held by the chuck. Luckily though, it still worked! I was able to fully lodge the micrometer inside of the custom 3D printed casing. One small drawback - while recording the drilling process for Stardance, I had completely cracked my phone case from the flying bits of PETG-CF created by the drilling. This was an absolute wakeup call to use my safety glasses. Highly reccomend!
	- I also drilled the 10X lens' casing to create an opening for the red laser's light to pass through. Initially, I was using the same diamond drill bits, but later decided to switch to a speed step drill bit. This solved the wobbling issue and led to me making two uniform, clean holes both of the lens casing cover pieces. The semi-transparent plastic piece was by far harder to drill into, however - it felt much more brittle and prone to chipping. Thankfully, it did not pose any of such issues.
	- I reprinted the LMB by enlarging the hole from 28mm to 30mm (LMB02.stl).
	- Today, the bulk of my missing parts arrived. These were the long-awaited ThorLABS silvered mirrors, laser diode set, screwing set and heat insert kit. Now, the only components I am missing are the nickel rod and the beamsplitter. 
	- One pet peeve of mine was that the photodiode mounting bracket (PBM) was still not built - it is the last thing I need to truly call my design complete. Therefore, I used an online 3D model as a reference to get exact dimensions to make one! While still not the best, it should work to keep the photodiode aligned to the laser. 
	- I ended up 3D printing the minor components in the MMM crucial to the mirror adjustment system (MMM05.2.stl and MMM05.3.stl). I realized that the screwholes in MMM05.2.stl were printed slightly wrong - on one of the sides, the holes seemed to be almost closed off. This is due to printer error. The physical components found within those files will be referred to as MMM05.2 and MMM05.3 to avoid confusion.
	
	Decisions:
	D-023: I decided to scrap the DVD laser diode idea entirely. This is because adjusting the lens to perfectly align to the diode is required for a straight beam, and therefore, I would need to redesign the laser diode mount in a much more adjustable, complicated manner. The alternative option is simply to create a cylindrical hole to insert the already received and working laser diode I have anyway - a much simpler solution.

2026-08-23\
	Goal: Continue assembly of mounts onto the actual breadboard!\
	Time spent: 2h10min logged on Stardance
	Activities: Fixing MMM05.03's print, catching up on documentation, 
	- I used a 1/8 drill bit to open the closed off holes in MMM05.03. It was now perfectly compatible for the insertion of M3 screws.
	- I found that the springs from my DVD drive are wholly incompatible with M3 screws, as they are far too small.
	- For every hole in MMM05.03, I used M3x30mm screws which I fixed to this aforementioned mount. a flat washer, lock washer and nut to hold the screw in place. To mount MMM05.02, I used a nut followed by a lock washer on the left side and another nut on the right, securing it in place. 
	- I reworked the SMB (SMB01.X.stl) to include screws to stabilize the solenoid cover (SMB.01.2.stl). Previously, a cylindrical hole was the only thing keeping the solenoid cover in place, and the rear bracket (SMB01.1.stl) simply had free motion, which is horrible for our testing for rather self explanatory reasons? If not, I'll explain - we are measuring changes in the metal rod of only a few nanometers. If anything slightly impacts the rod or the bracket, the whole mirror system would become completely misaligned. Now, I am able to firmly hold the cover and the rear bracket in place. However, when printing it with the preset orientation, the print completely failed, leaving a mess of PETG filament all around. Now, I have rotated the model 90 degrees along the x axis using the Anycubic app.
	- I tweaked the file structure of all cad files to show which are iterations and which are final designs. This is to make the structure as straightforward as possible.
	
	Decisions:
	D-024: I decided to scrap the idea of using DVD drive springs to finely adjust the mirror mounts. This is because they are wholly incompatible with my present systems (too narrow AND too short), meaning I would have to either magically enlarge them, find a way to source new springs, or find an alternative which still allows me to firmly mount the two plates using the screws, locks and washers which are currently at my disposal. For now, I am choosing the latter option.
	D-025: In the Github, iterations (unfinished versions of the CAD designs) and final (complete versions of the CAD designs) files will be separated in two distinct folders.

I am currently rather concerned about finalizing the project on the September 1st goal date, as the beamsplitter is expected to arrive from August 25-28th, leaving me with only a few days of real testing.

2026-08-24\
	Goal: Continue 3D printing and mounting to the spoilboard\
	Time spent: 1h14min logged on Stardance\
	- Today, I printed the SMB, and assembled it onto my spoilboard. This took a surprising amount of time, as the tolerances for the main adjustment bracket screws seem to not have been accounted for. However, this made my brackets despicably firmly attached, which isn't necessarily a bad thing.  The screws linking the solenoid cover to the  adjustment brackets were also very firm despite tolerance being accounted for (M4 screws and 4.20mm hole), though I suspect my 3D printer was a slight cause for this unexpected attribute. However, the mirror mounting system's screwholes were simply too small for their M3 screws, as in this case, tolerance was AGAIN not accounted for. I drilled the holes using a 1/8 bit to allow the M3 screws to fit into the design whilst allowing them some room for adjustability. The nuts and lock washers are the real thing keeping anything in place with my system, so slight tolerance should not be an issue.
	- I also redesigned the LDM to account for the new laser diodes I have bought. In terms of design, it is now almost the same as the LMB, with a cylindrical opening to accommodate the laser, and a screwhole (this time, on the right rather than on the top) to keep it firmly in place. I printed it without facing many issues.
	- I also connected with a physics professor for an opportunity to see a real, optical grade interferometer! Sadly, this is on August 31st, so, according to the deadline objective, I would only have one day to iterate based on the assessed knowledge from this experience. Nonetheless, still cool! 

2026-08-25\
	Adjusting BSM mount and laser mount\
	Time spent: 19min (2min logged on Stardance)\
	- Today, I tried printing  the BSM mount to no avail. The primary issue I found was the alignment - the two larger screwholes for mounting the lower component to the spoilboard were also misaligned to the plate. I fixed this my moving each insert, as well as their respective outer cylindrical platforms which allow the screw to be fully lodged in, away from the center by 2.5mm on both sides. This expands the screw alignment by 5mm, which is correct based on my measurements, and ended up working as intended.

2026-08-26 
	Goal: Fix BSM mount\
	Activities: modifying and reprinting BSM mount, instaling LDM and BSM to spoilboard\
	Time spent: 25min logged on Stardance\
	- Today, I tried assembling the BSM mounting system to the spoilboard, but there were several more problems with its lower component. 
	- Firstly, the major spoilboard holes for what I intended to be M5 screws were way too large, whilst also being way too shallow for heat inserts. I decided to reduce them to 5.05mm in diameter to allow only very slight tolerance to the M5 screws. 
	- Secondly, the boss in this lower component was of a diameter far too large to accommodate M3 screws, yet too small to accommodate M3 screw heat inserts or M4 screws. I adjusted the diameter to be 4.05mm - now, M4 screws properly fit in the frame, too. 
	- Secondly, the bosses went slightly past the outer walls designed to support the top BSM component - to fix this, I added a central surface to the bottom mount delimited by two larger cylinders to prevent issues with screwing in/adding locks/nuts to the lower screws, which link the component to the spoilboard. Overall, I ended up with this design, which was adequate for my needs without the use of heat inserts.
	  - I also finally mounted the LDM to the spoilboard, and found no further issued with the design. 
	`Decisions:`
	`D-025: I decided to scrap the heat inserts entirely, as of now. If they are re-instated, I will repeal this decision, but the set of locks, nuts, washers and screws is currently able to make an already very rigid assembly for my components, which I judge to be rather indiferrent to that of using heat inserts - which would require reprinting some of the parts used.`

2026-08-27
Goal: write devlog 
	Time spent: N/A
	Activities: writing the devlog.
	Today was rather brief. I am waiting on the beamsplitter to arrive to take the steps to finalize my project, as school is now beginning to get in the way. 

2026-08-28
	Goal: catch up on documentation!
	Actrivities: Journaling, experimenting with beamsplitter and mirrors
	Time spent: 1h22min on Stardance
	- I spent most of my time tabulating and reformatting the journaling which has been done in the last couple days. This is to ensure that my formatting is more uniform across all days.
	- Today, the beamsplitter finally arrived! I was therefore able to test whether the BSM's printed components (BSM.1.0X) were suitable for my system -  they were not. However, the mirrors did fit perfectly within their respective mirror mounts, which was great! I left the reiteration of the BSM mounts for tomorrow, however.
	
2026-08-29
	Goal: Reprint BSM, make first real alignment tests.
	Activities: Reprints, remounting components, soldering laser wire, first alignment test
	Time spent:
	Lots of progress today!
	-Today, I redesigned the top BSM insert to be slightly larger (BSM3.02) and printed it! It is to note that there was an earlier printed version, (BSM2.02, which had some tolerance but still didn't properly allow for the insertion of my beamsplitter). The insert size ultimately changed from 20.0x20.0mm to 20.5x20.5mm.
	-I glued the SMB's mirror mounts to the nickel rod using and the MMM's plate mirror mount to the micrometer using hot glue, hoping that this would make the mounts stick more firmly and allow for easier adjustment. After this failed, and the MMM mirror mounts came off shortly after, I realized I needed to redesign the MMM mirror mount to have a small insert to fit the mounts to the micrometer. This would improve stability and hot gluing potential, as it increases the contact surface area to the 3D print.
	- I soldered the red laser diode to the designated red and black wire in my circuit, as it was getting annoying to manually align the cables. This makes it now possible to test interference, and to power the diode without the use of my hands.
	- For this reason, I put together all optics together and ran a real alignment test of my system, with the laser, beamsplitter, mirrors and lens all in place for the calibration phase. The light went through the lens, but it wasn't recombined and no fringes showed up - In their place were laser speckles, which randomly appear due to microscopic scattering when hitting a rough surface (in this case, the paper I used.)
	- The laser was also misaligned with the MMM -  the laser pointed slightly too far to the left and down, which means the light from this first mirror would be completely deflected in a different direction. 
	- Additionally, the SMB solenoid cover was also measured to be 4mm too low, which meant the laser sometimes hit the top or be seen reflected on the mounts.

2026-08-30
	Time spent: 43min logged on Stardance\
	Moderate progress today. Topics to talk about\
	 -more reprints (particularly SMB ones which all failed, anycubic slicer)
	 -MMM reprint, hole had to be drilled with 7/32 bit (5.49mm diameter)
	 -Tinkercad revisions of LMB and LDM to account for alignments 
	 -Assembling with new solenoid cover which is now more aligned!!
	 - Laser focal point adjustment
	 - MMM reprint, hole had to be drilled with 7/32 bit (5.49mm diameter)
	 - Deadline concerns: it is likely not being completed as a project tommorow...
	 - As of now, 3 parts in the final section remain to be printed.

2026-08-31
	Time spent: 1h45min logged on Stardance\
	Lots of progress today! Topics to talk about:
	- Assembling MMM mirror mount again
	- Mounting the new LDM to adjust the laser
	- Aligning compoennts
	- Recombining light through the lens - Assuming no vibrations, this would mean interferometry successful!
	- Printing new solenoid cover

2026-09-01
	Time spent: 3h06min \
	Progress today: 
	 -Assembling SMB with new, improved solenoid cover (printed well this time) success
	 -Resoldering GND wire for laser and using borrowed electrical tape to keep it in place
	 -Alignment - aligning two lasers in the lens yet, still no desired interferometry (though found Newton Interferometry on accident, not as useful) trick found with holding small piece of paper at laser origin to find divergent lasers and align them!
	 -Printing new LMB
	 -Images!

	 Idea for alignment: put rulermarkings on the spoilboard to know distance to mirrors from beamsplitter at ALL times (requires dissassembly of much of the present elements in the system) + move laser closer + Removing nuts/washers in the mirror mounting systems + hot glue mirror mount 1 to micrometer

2026-09-02
	Goal: create alignment guide for precise adjustment, \
	Activities:\
	Time spent: 59min logged on Stardance
	
Progress today:
	-Dissasembly of most components from the spoilboards to make alignments guides on the MDF plate\
	- Creation of alignment guide'\
	- setting mirrors to same distance\
	- designing new LMB (LMB04)

2026-09-03:
	Goal: Mount new LMB (LMB04)\
	Activities: Mounting lmb\
	Time spent: N/A logged\
	Topics: remounting LMB and rest of mounting system

2026-09-04:
	 Goal: Journaling\
	 Activities: bringing documentation to be more up to date and precise.\
	 Time spent: 42mins logged on Stardance\
	 To do: FIX TIMES starting 2026-09-01.\
2026-09-05:
	Goal: see fringes\
	Time spent: 
	Topics: alignmennt of laser - This was what caused most problems for me today.
	The fact that most mounts is now adjustable and modular seems like an upside, but is proving to be rather detrimental.\
	-Dust got on mirror 2: Assessed failiure cause: window was open, even with filter, this gets dust from outside trapped in. My window is broken, so it cannot close with the arm, so I therefore closed it manually, but not before dust got it,. and has been getting in for days. I attempted to lightly applyu a microfiber cloth, yet found out that this is rather dangreous, as dust particles couild scratch the mirror. Luckily, my mirror seems unscathed, but unfortunately, this led to be going over budget.\
	I purchased an air blower and a pack of optical film wipes, as none could be found in my house. This unfortunately brings my total cost to 376.40$. (But gives me the peace of mind that this project can be feasible and sustainable!)
Here is the two items I bought:

| Item | Price (CAD) |
| --- | --- |
| ** [ZEISS Pre Moistened Sunglasses Cleaning Wipes, 120 Count](https://www.amazon.ca/dp/B0FT4WPV5F)** | 20.69$ (On sale, usual price: 22.99$) |
| **[Soft Tip Silicone Super Air Blower Blaster Pump Dust Cleaner Include Micro Fiber Cleaning Cloth, Bulb Blower](https://www.amazon.ca/dp/B07Y1TKXVK)** | 13.99$ |

Idea: instead of using hot glue, using jammed matchstick pieces as a wedge could make my connection much more solid. I am therefore strongly considering this possibility.

2026/09/06
	Goal: Make alignment easier\
	Topics: I made alignment guide markings for the laser as well, using a fine tip mechanical center. I used a ruler to make precise translation step references and an angle protractor to create a semi-circular guide. While aligning, I can use the angle protractor to see roughly now many degrees the reflected images are off by with a piece of paper.

2026/09/09
	Goal: Properly visaualize interferometric fringes 
	Activities: Aligning the optical components precisely to observe fringes.
	Time spent (1h24min, 0 logged on Stardance)
	-I added a new initial procedure to my experiments - cleaning the surface and room for the interferometer using a vacuum cleaner before starting, and that all windows/ventilation is closed or kept to a minimum. This will ensure the environment is as dust free as possible.\
	-Unfortunately, this phase of the experiment is one which I cannot log on Stardance - the computer must be turned off at all times to minimize vibrations which would perturb the experiment, and, on mobile, the very low brightness required to see the expanded fringe image with the lens, making the recording freeze due to no changes in activity being reported. Annoying enough - but not the end of the world. \
	-One issue which I encountered today was that of lens alignment. The lens translation works perfectly,. but, when the laser beam is perfectly aligned with the beamsplitter and mirrors, unlike before, the image appears higher. By using a cut piece of poster paper and manually moving the lens up until it reaches the image, then marking key points with a mechanical pencil, I estimated that the lens was between 3.0-4.0mm too low respective to the image height. Therefore, I should print a new beamsplitter which factors in this height.\
	-However, I was able to spot the first actual Michaelson Interferometry in my project. This was by re-hot-gluing the MMM mirror mount to the micrometer (inoptimal, I know...) and adjusting the length to the beamsplitter mount to 3.8cm for both mirrors. I saw 6-7 distinct rings of darkness form. However, the strange thing is that if the mirrors were made have their images unaligned, interferometry (fringes) still occur on both the images. According to my understanding of interference, this should NOT occur in the Michaelson interferometer! However, once misaligning the lengths of the two mirrors, the fringes dissappear once again, confirming that they are true Michaelson Interferometry waves. My research has not led to any reasonable explanation for this phenomenon. Success (?)\
	`-Idea: LMB with plates and vertical rails. Much like adding weights works in a gym, adding plates under the LMB and making the larger system modular could allow for height to be semi-adjustable - but much mroe than it is now.`

2026/09/10
	Goal: Fix LMB mount height\
	Time spent: 18 mins\
	Activities: Slightly raising LMB mount design by 3.5mm to account for yesterday's observations. 

2026/09/13
	Goal: Get even BETTER images thanks to new LMB, and funding request resubmission\
	Time spent: 1h21min logged on Stardance
	Activities: assembling new LMB to spoilboard, adjusting interferometry ~~ritual~~ alignment. documentation\
	- Today, I printed the LMB, remounted the new LMB to the spoilboard and re-ran the interferometry calibration procedure. Speaking of which, I MADE a proper interferometry calibration protocol - see the README.md file!\
	- I was able to capture the smoothest example of interferometry I have observed thus far. The rings were distinct and crisp, reacting to even the slightest of vibrations. \
	- The  multi image effect was, once again, spotted. This time, however, I noticed that an indescribably fascinating phenomenon was occurring whilst I slowly shifted angle of one of the mirror angles into place - The rings weren't changing place, but amplifying in intensity after a couple seconds as the mirrors aligned back into place. \
	- I deemed that, with this level of interferometry, it may be possible to now consider the electronic measurement system, officially entering a new, long awaited phase in this project's development. \
	- I decided to move forward to resubmit my project for a funding request on Stardance. This means that my BOM was updated with new items and the 3d .stl files were submitted separately once more, as .step files (as to comply with Stardance rules.)

2026/09/14
	Time spent: 1h00min (N/A logged on Stardance)\
	Activities: Viewing of PROPER Michaelson interferometer which uses a sodium lamp to create proper fringes. \
	- Advice/idea: Rework MMM to be more solid. Today, I was able to bring my interferometer to my college, which allowed me to get meaningful input from two physics professors. The main critique was that my MMM was way too flimsy, and since the micrometer moves helicoidally and the guides are meant for translational movement, meaning that the movement exerted heavy rotation on the mirror mount. The hot glue exacerbated this problem by creating additional friction.\
	- I found that Michaelson fringes move depending on the viewing angle, alike what I partially saw in my own system, suggesting that my system somewhat was making fringes resulting from recombined light as intended. However, these were much more crisp, and no non angle dependant rings (as in my system) were present. We concluded that some these rings on my system were due to imperfections in the lens causing Newton interferometry.

2026/09/16
	Goal: Get even BETTER images thanks to new LMB
	Activities: CAD work - new MMM supports, ordered epoxy glue
	Time spent: 27min logged on Stardance
	- Today, I focused my time on ensuring that the guides for the MMM could be reinforced, making a system which allows smooth translation for the mirror mount. I took the two lateral M6 threaded screws on the spoilboard that the MMM already uses to serve as a reference for where these guides should go. I then added another mounting hole for the next two M6 threaded inserts towards the center - that way, both guiding mounts would be firmly attached to the main system. I made heavy use of fillets throughout the design to decrease stress, except at one point - the side walls facing the MMM, where the guide needed to restrict the mirror mount's movement. I allowed a +-0.5mm tolerance on each side for the mirror mounting components - That way, the adjustment screws can still be tuned, but the movement of the MMM stays strictly forward as the micrometer moves. I also extended the length of these side walls to be equal to that of the MMM's pre-existing guides and bumper post, to make the design more coherent and make sure that the guides remain around the mirror mount at all times. I made the inner wall height double that of the MMM's screw bracket, as to be able to properly mount the screw bracket, outer wall guides and a nut using the M6x30mm screws.

I also ordered epoxy glue, as reccomended by my professors:

| Item | Price (CAD) |
| --- | --- |
| **[Gorilla Glue Epoxy, Dries Clear, Gap Filling, Indoor & Outdoor, Water Resistant, 5 Minute Set, Dries Clear Transparent, 0.85oz/25mL, (Pack of 1) 4200602](https://www.amazon.ca/dp/B07W6C9R4K)** | 13.49$ |
This brings my total budget to 390.37$. It is arriving on 2026/09/18.
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

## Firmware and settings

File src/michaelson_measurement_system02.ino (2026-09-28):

/*
  Analog input, analog output, serial output

  Reads an analog input pin, maps the result to a range from 0 to 255
  and uses the result to set the pulse-width modulation (PWM) of an
  output pin (the illumination LED). Also prints the results to the
  serial monitor.

  The circuit:
  * light sensor (photodiode/phototransistor) connected to analog pin A0.
    Center pin of the sensor circuit goes to the analog pin. Side pins
    go to +5V and ground (with appropriate pull-down/bias resistor).
  * Illumination LED connected from digital pin 9 to ground (through a
    current-limiting resistor), on a PWM-capable pin.

  created 29 Dec. 2008
  modified 26 Sept. 2026
  by Raoul Zachary Docteur Salemi
  This code is in the public domain.
*/

int sensorValue = 0;
int outputValue = 0;

const int sensorPin = A0;
const int ledPin = 9;   // must be a PWM-capable pin (3, 5, 6, 9, 10, 11 on Uno)

// Helper function to reject 60Hz/120Hz noise via 16.667ms window integration
int readMainsFilteredSensor(int pin) {
  long sum = 0;
  int samples = 0;
  unsigned long startTime = micros();

  // Accumulate readings across exactly 1 full 60 Hz / 2 full 120 Hz cycles (16,667 microseconds)
  while (micros() - startTime < 16667) {
    sum += analogRead(pin);
    samples++;
  }

  if (samples == 0) return analogRead(pin); // Fallback safeguard
  return (int)(sum / samples);
}

void setup() {
  pinMode(sensorPin, INPUT);
  pinMode(ledPin, OUTPUT);
  Serial.begin(9600);
}

void loop() {
  // Turn on the illumination LED
  digitalWrite(ledPin, HIGH);

  // Read the detector output with 120 Hz line noise rejection
  sensorValue = readMainsFilteredSensor(sensorPin);

  // Convert 0-1023 ADC reading to 0-255 PWM value
  outputValue = map(sensorValue, 0, 1023, 0, 255);

  // Drive LED based on measured light intensity
  analogWrite(ledPin, outputValue);

  Serial.print("sensor = ");
  Serial.println(sensorValue);

  // Small delay between output iterations (adjust rate as needed)
  delay(10);
}

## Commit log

2026-08-02 Added TinkerCAD source code, just in case :)
2026-08-03 Added magnetostriction components to README
2026-08-03 Update resistor value from 10kOhm to 50kOhm
2026-08-11 Changed README.md flow for readability
2026-08-11 Updated magnetostriction description in the intro
2026-08-19 Added images to CAD documentation
2026-08-19 Updated units and prices to reflect real amounts post-purchase
    [BOM.csv]
2026-08-23 Update JOURNAL.md
    Updated journal entries with detailed activities, decisions, and reflections on project progress, including adjustments to CAD designs and sourcing of components.
2026-08-23 Update decision D-015
    Expanded on the benefits of using grid paper as a screen for the interferometer, mentioning improved laser fringe clarity compared to alternatives like MDF, cardboard, and PVC.
2026-08-23 Revise laser diode and screws specifications
    Updated the specifications for the laser diode and screws in the README.
2026-08-29 Update BOM.csv to add new items and prices
    [BOM.csv]
2026-08-29 Update BOM.csv with new items and prices
    [BOM.csv]
2026-08-29 Update BOM.csv with price after sales tax
    [BOM.csv]
2026-09-14 Added 3D printing section and testing details
2026-09-16 Add new STEP file MMM07.5.step
    [MMM07.5.step]
2026-09-20 Rename Screenshot 2026-08-02 085014.webp to Helios - Tinkercad wiring schematic
2026-09-20 Improve calibration instructions in README.md
2026-09-28 Clarify laser type and add measurement results
    Updated the description to specify the use of red laser light and added results from the electronic measurement protocol.
2026-09-28 Add MMM01.2.step file
    [MMM01.2.step]
2026-09-28 Add MMM01.3.step file
    [MMM01.3.step]
2026-09-28 Rename IMG_3755.jpeg to Helios - Magnetostriction test 01.jpeg
2026-09-28 Added magnetostriction image
2026-09-28 Rename Helios - Tinkercad wiring schematic.png to Helios - Tinkercad wiring schematic 01.png
2026-09-28 Revise README with updated abbreviations and images
    Updated mounting bracket abbreviations and added finalized images for various components. Revised figure references for wiring diagrams and results.
